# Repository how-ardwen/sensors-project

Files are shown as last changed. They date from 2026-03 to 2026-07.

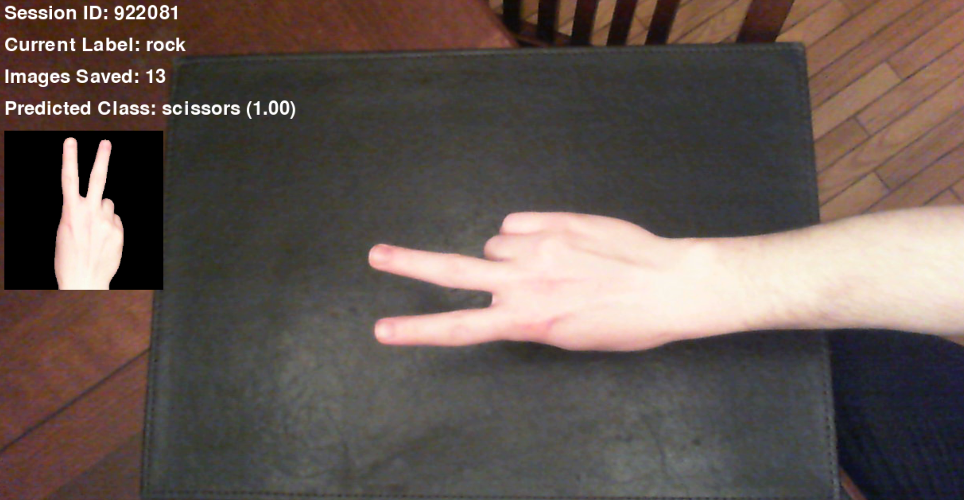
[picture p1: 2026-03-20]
cv_src/prof/HandPhotos/Testing/scissors_02.png

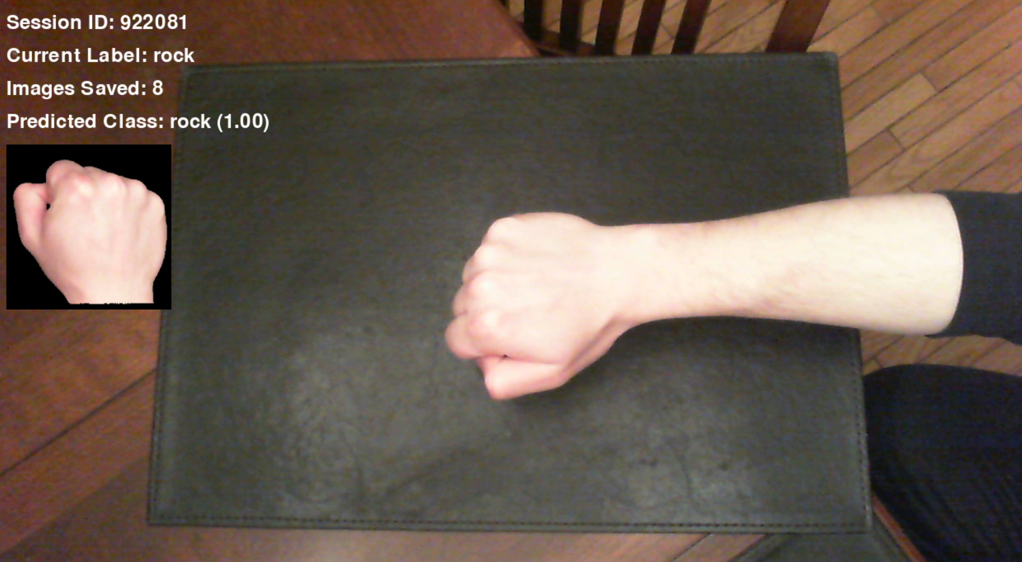
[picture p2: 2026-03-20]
cv_src/prof/HandPhotos/Testing/rock_01.png

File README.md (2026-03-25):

## Communication Protocol

Three ESP32 microcontrollers each connect independently to the laptop over BLE.

---

### MCU 1 — Left Arm  (`RPS-MCU1`)
### MCU 2 — Right Arm  (`RPS-MCU2`)

Packet format: **`H[sign]\n`** (3-byte ASCII + newline)

| Field | Description |
|---|---|
| `H` | Header byte (hand gesture command) |
| `sign` | Gesture code (see table below) |
| `\n` | Newline terminator |

**Gesture Encoding:**

| Value | Gesture | Pinky+Ring | Index+Middle | Thumb |
|---|---|---|---|---|
| `0` | Neutral (rest) | open | open | open |
| `1` | Rock | closed | closed | closed |
| `2` | Paper | open | open | open |
| `3` | Scissors | closed | open | open |

> Neutral (0) is mechanically identical to Paper — all fingers open.

---

### MCU 3 — Swivel Controller  (`RPS-MCU3`)

Packet format: **`S[arm]\n`** (3-byte ASCII + newline)

| Field | Description |
|---|---|
| `S` | Header byte (swivel command) |
| `arm` | Which arm to swivel out of the game window |
| `\n` | Newline terminator |

**Arm Encoding:**

| Value | Action |
|---|---|
| `0` | Both arms in frame |
| `1` | Swivel **left** arm (MCU 1) out of frame |
| `2` | Swivel **right** arm (MCU 2) out of frame |

---

### BLE Service (all three MCUs — Nordic UART Service)

| UUID | Role |
|---|---|
| `6e400001-b5a3-f393-e0a9-e50e24dcca9e` | NUS Service |
| `6e400002-b5a3-f393-e0a9-e50e24dcca9e` | RX Characteristic — laptop writes here |
| `6e400003-b5a3-f393-e0a9-e50e24dcca9e` | TX Characteristic — reserved for future use |

---

### Example Game Flow

| Step | Packet | Target | Meaning |
|---|---|---|---|
| Stage 1 | `H1\n` | MCU 1 | Left arm shows Rock |
| Stage 1 | `H3\n` | MCU 2 | Right arm shows Scissors |
| Stage 2 | `S1\n` | MCU 3 | Swivel left arm out of frame |

Other header bytes are reserved for future message types (e.g., `R\n` for reset).

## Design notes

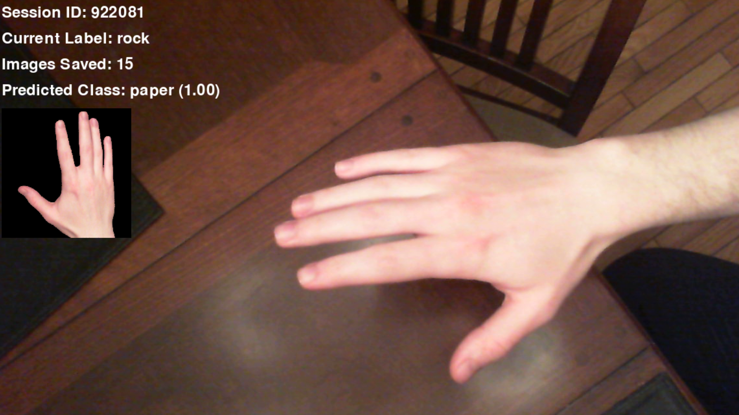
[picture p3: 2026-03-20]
cv_src/prof/HandPhotos/Testing/paper_02.png

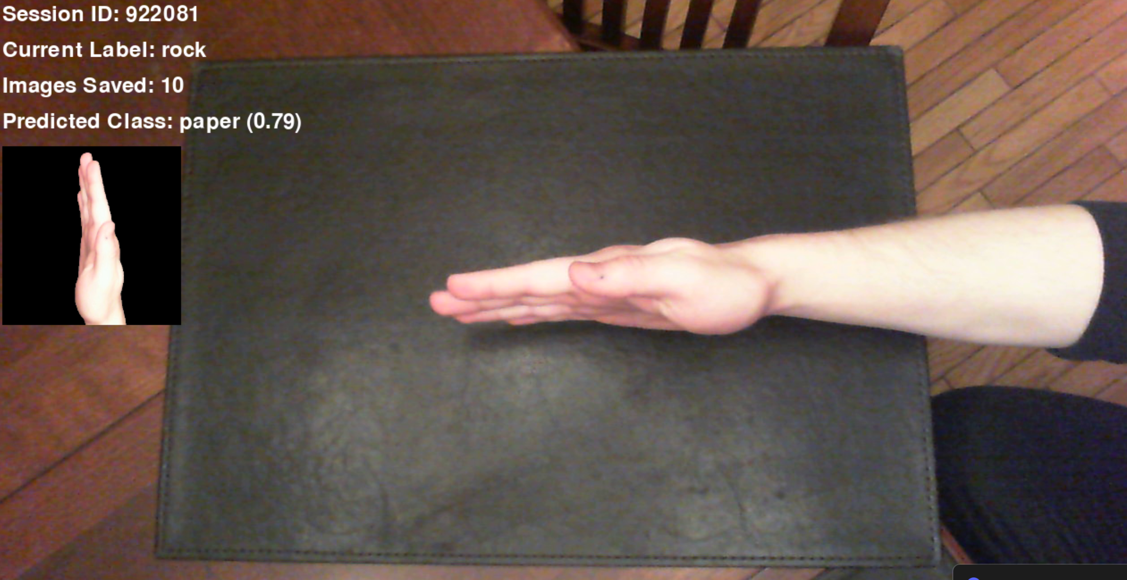
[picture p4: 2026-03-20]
cv_src/prof/HandPhotos/Testing/paper_01.png

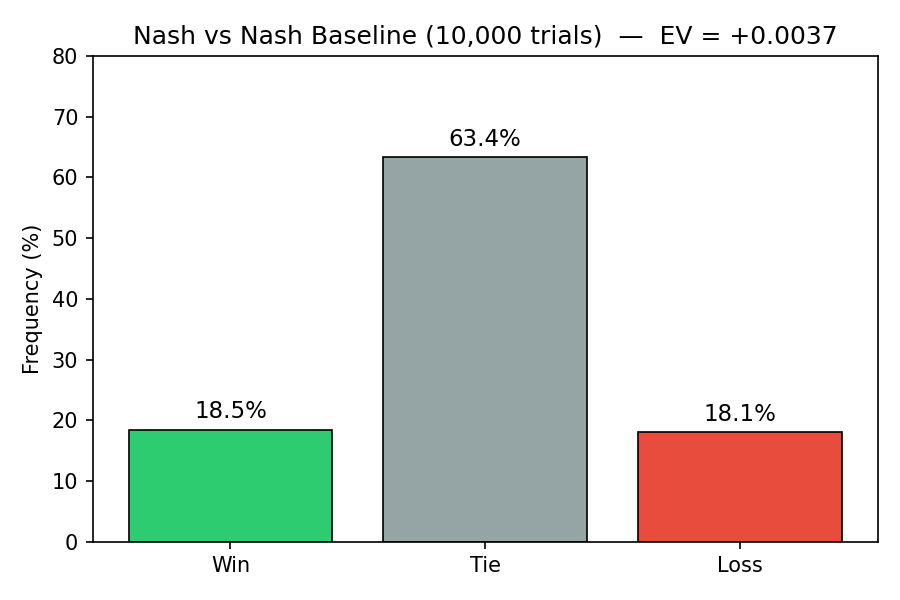
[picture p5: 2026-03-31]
figures/nash_vs_nash.png

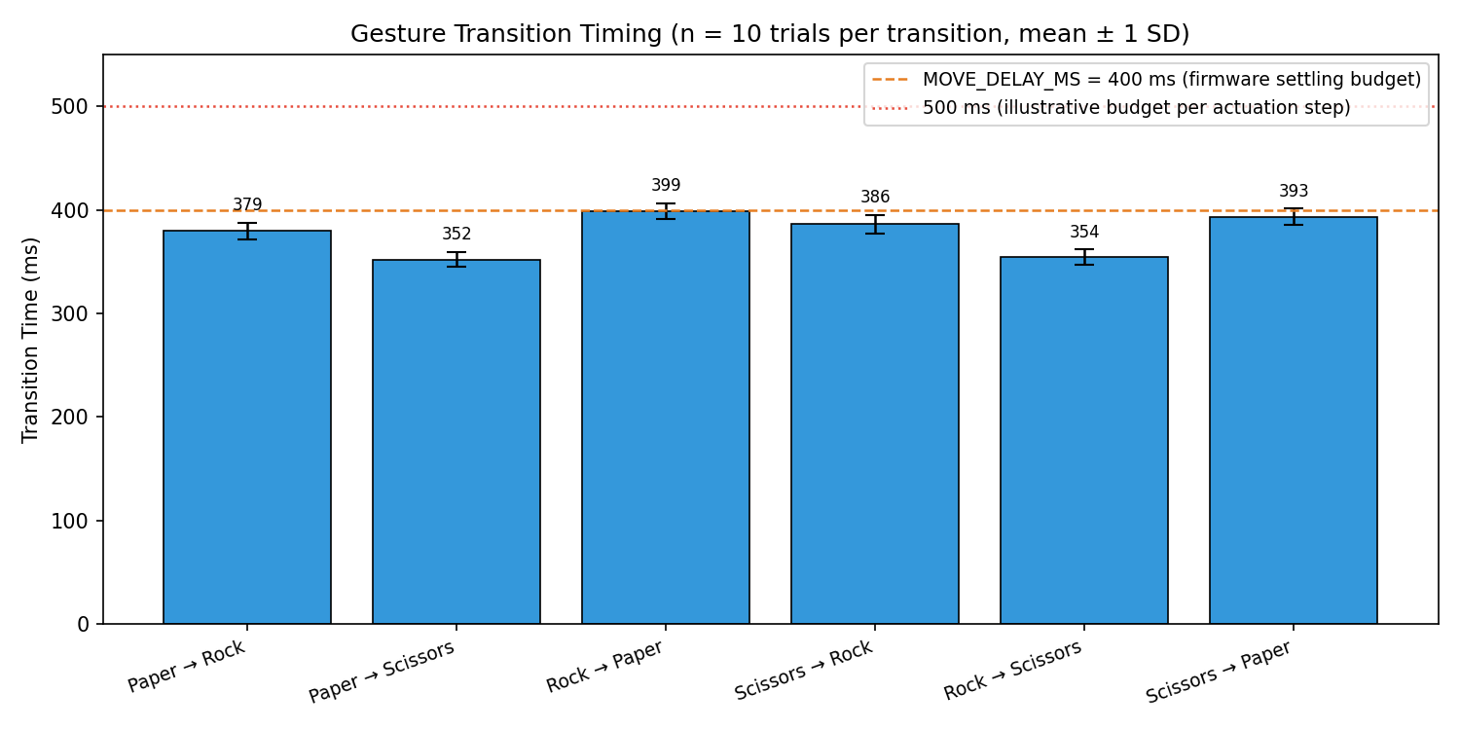
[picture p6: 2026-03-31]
figures/gesture_timing.png

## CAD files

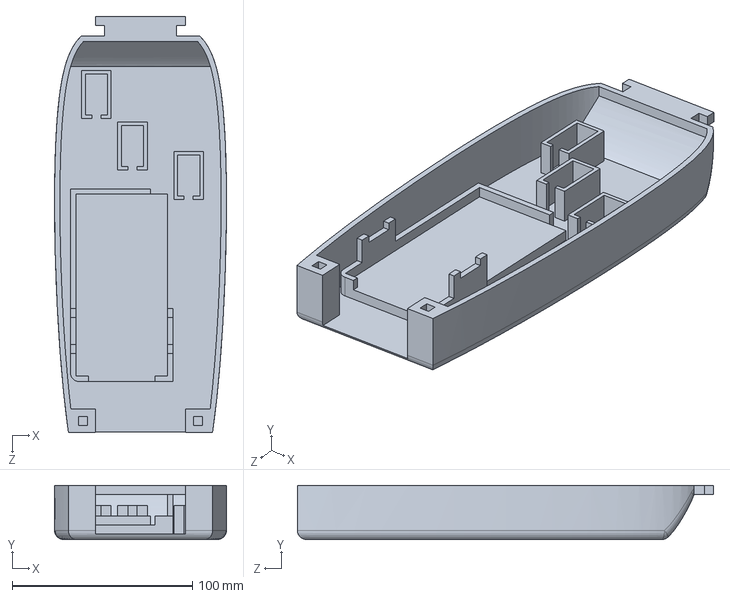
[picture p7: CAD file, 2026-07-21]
CAD/Forearm/Forearm.SLDPRT
95.5 x 30.0 x 231.0 mm

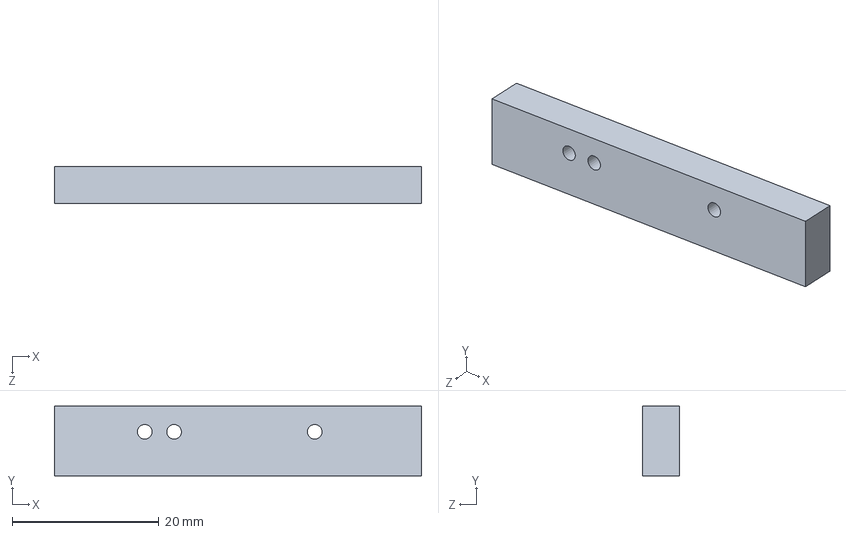
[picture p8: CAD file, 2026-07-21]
CAD/Left_Hand/Left_Hand_Routing_Block.SLDPRT
50.0 x 9.50 x 5.00 mm

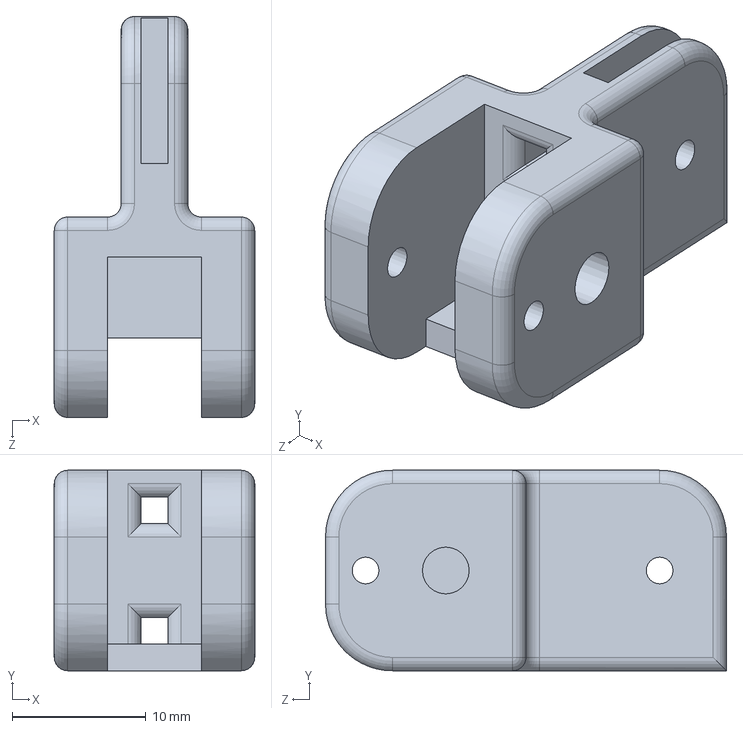
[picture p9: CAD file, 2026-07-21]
CAD/Pointer_Finger/Pointer_Finger_Middle_Section.SLDPRT
15.0 x 15.0 x 30.0 mm

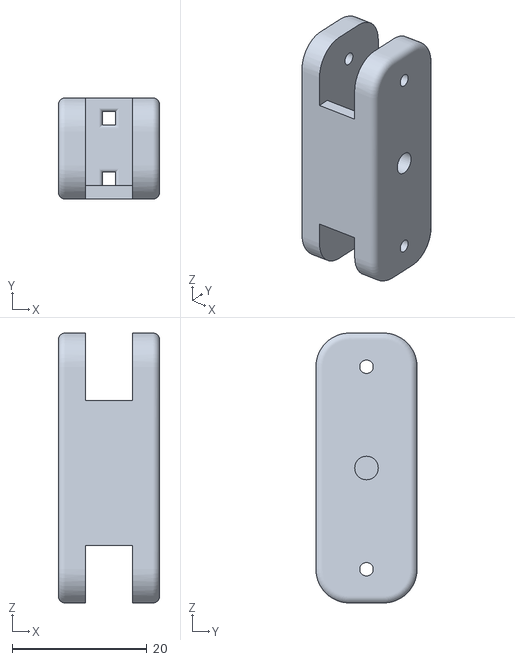
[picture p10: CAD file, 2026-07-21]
CAD/Print_Files/Pointer_Finger_Bottom.STL
15.0 x 15.0 x 40.0

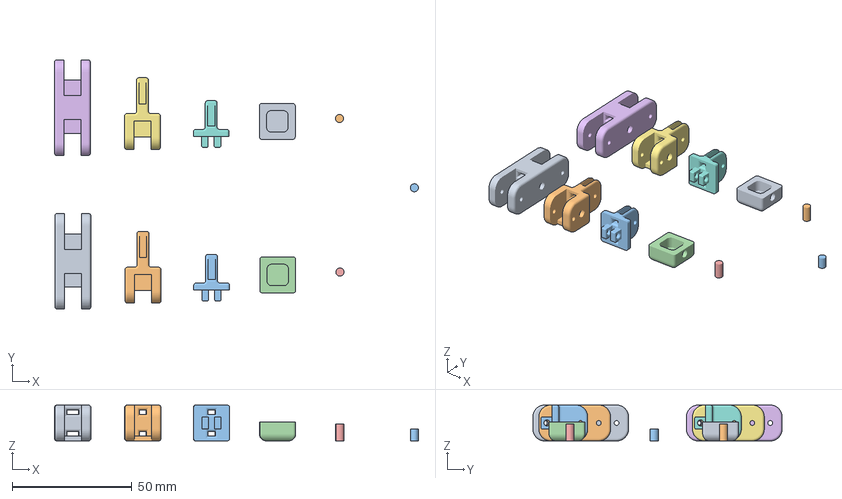
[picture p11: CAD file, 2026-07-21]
CAD/Print_Files/v4/Twofingers.3mf
152.0 x 104.1 x 15.0 mm
Pointer_Finger_Bottom.STL x 2
Pointer_Finger_Middle_Section.STL x 2
Pointer_Finger_Tip.STL x 2
Pointer_Finger_Tip_Cover.STL x 2
Finger_Joint_Connector.STL x 2
Finger_Tip_connector.STL

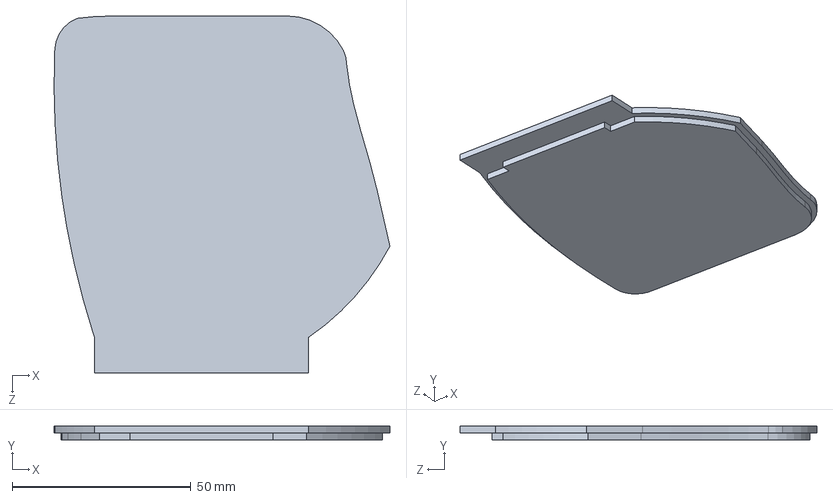
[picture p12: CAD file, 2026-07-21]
CAD/Right_Hand/Palm_Top.SLDPRT
94.1 x 4.00 x 100.0 mm

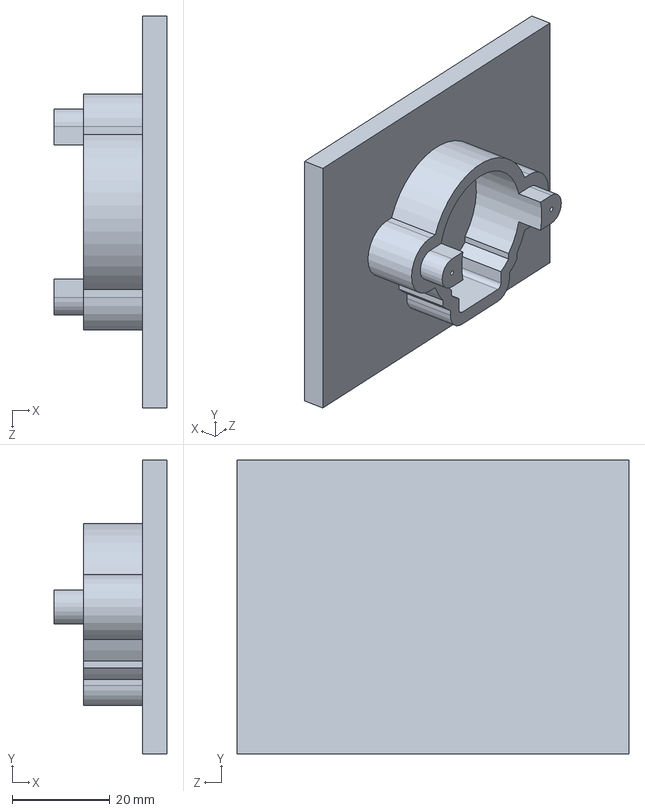
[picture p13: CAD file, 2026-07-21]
CAD/Stepper_Motor_Stuff/Part1.SLDPRT
23.0 x 60.0 x 80.0 mm

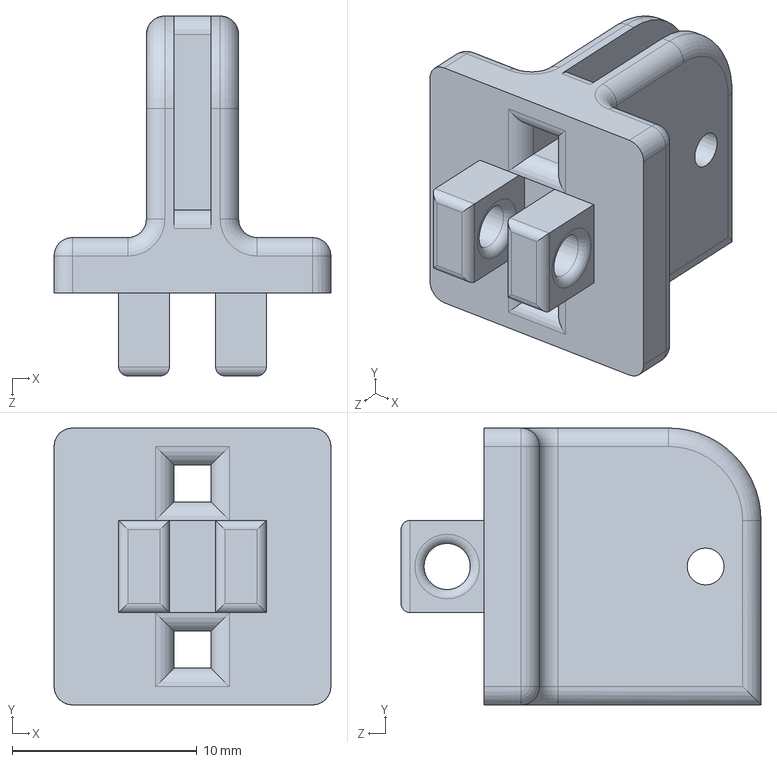
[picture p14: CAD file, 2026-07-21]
CAD/Thumb_Finger/Thumb_Finger_Tip.SLDPRT
15.0 x 15.0 x 19.5 mm

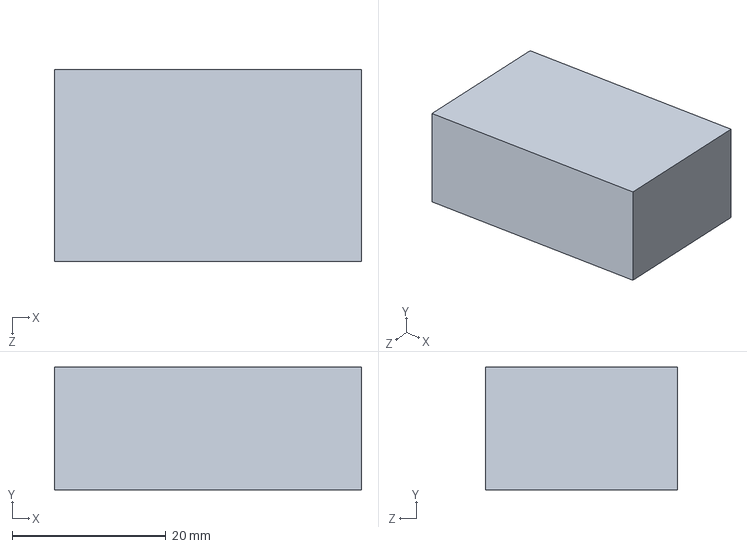
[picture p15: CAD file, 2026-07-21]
CAD/Wheel_Spacers.SLDPRT
40.0 x 16.0 x 25.0 mm

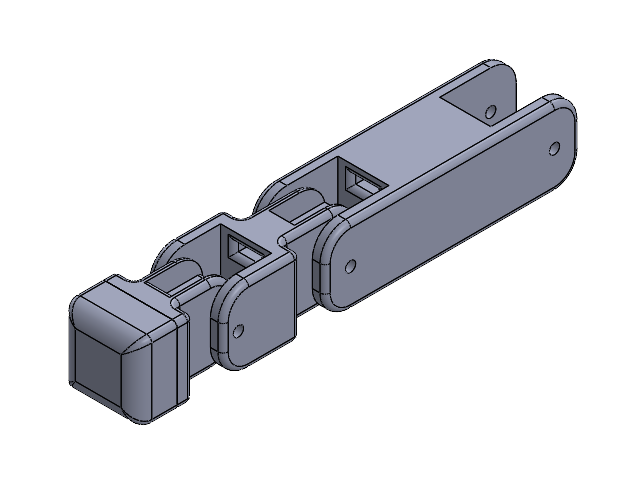
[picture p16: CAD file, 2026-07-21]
CAD/Middle_Finger/Middle_Finger_Assem.SLDASM
Middle_Finger_Bottom
Middle_Finger_Middle_Section
Middle_Finger_Tip
Middle_Finger_Tip_Cover

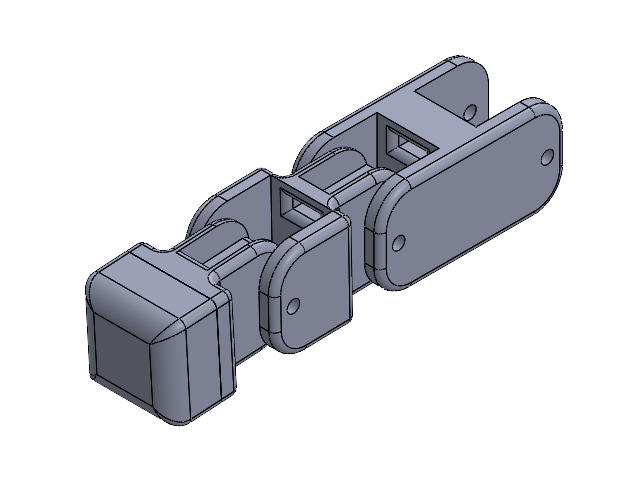
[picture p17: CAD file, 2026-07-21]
CAD/Ring_Finger/Ring_Finger_Assem.SLDASM
Ring_Finger_Bottom
Ring_Finger_Middle_Section
Ring_Finger_Tip
Ring_Finger_Tip_Cover

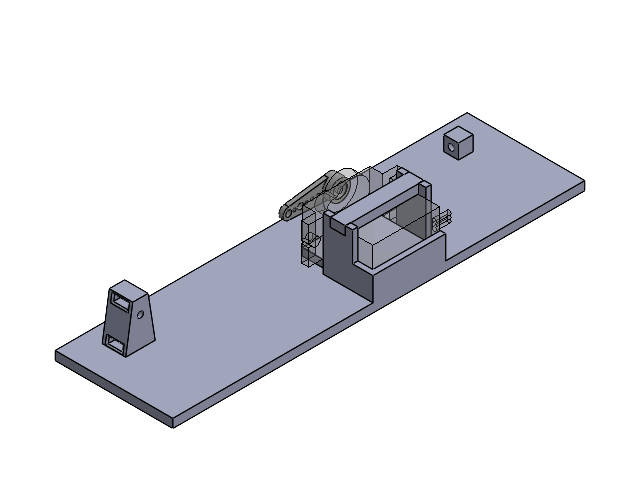
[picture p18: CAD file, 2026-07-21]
CAD/Test_Mount/Test_Mount_Sub_Assem.SLDASM
Test_Mount
servo 25
servo arm single
Servo Holder

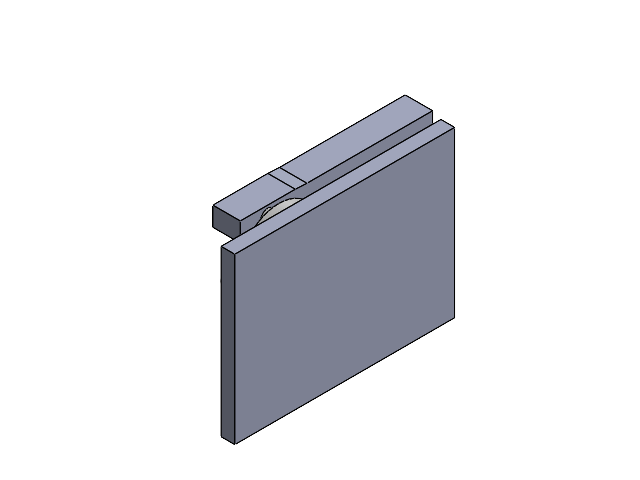
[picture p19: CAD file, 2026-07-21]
CAD/Stepper_Motor_Stuff/Stepper_Test_Assem.SLDASM
Stepper motor 28BYJ-48 5V

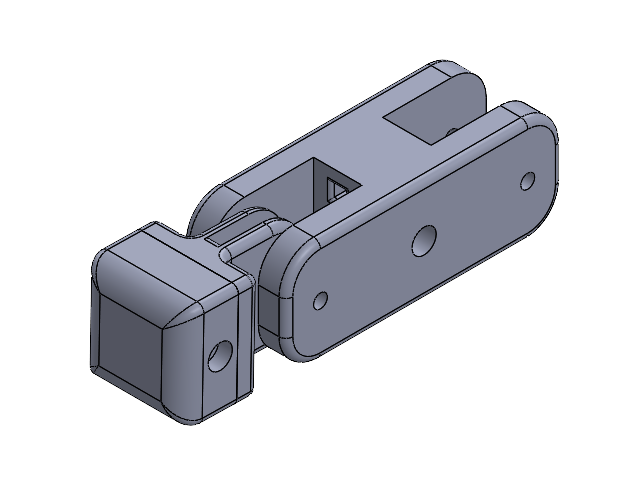
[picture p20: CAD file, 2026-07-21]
CAD/Thumb_Finger/Thumb_Finger_Assem.SLDASM
Thumb_Finger_Bottom
Thumb_Finger_Tip
Thumb_Finger_Tip_Cover

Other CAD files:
CAD/Forearm/Servo_And_Pulley_SubAssem.SLDASM
CAD/Left_Hand/Left_Hand.SLDASM
CAD/Pointer_Finger/Pointer_Finger_Assem.SLDASM
CAD/Right_Hand/Right_Hand_Assem.SLDASM
CAD/Forearm/Forearm_Smaller.SLDPRT
CAD/Forearm/extender_5mm.SLDPRT
CAD/Forearm/servo-pulley-SG90.SLDPRT
CAD/Left_Hand/Left_Hand_Forearm_Bottom.SLDPRT
CAD/Left_Hand/Left_Hand_Palm_Bottom.SLDPRT
CAD/Left_Hand/Left_Hand_Palm_Top.SLDPRT
CAD/Middle_Finger/Middle_Finger_Bottom.SLDPRT
CAD/Middle_Finger/Middle_Finger_Middle_Section.SLDPRT
CAD/Middle_Finger/Middle_Finger_Tip.SLDPRT
CAD/Middle_Finger/Middle_Finger_Tip_Cover.SLDPRT
CAD/Palm_Bottom.SLDPRT
CAD/Pointer_Finger/Finger_Joint_Connector.SLDPRT
CAD/Pointer_Finger/Finger_Tip_connector.SLDPRT
CAD/Pointer_Finger/Pointer_Finger_Bottom.SLDPRT
CAD/Pointer_Finger/Pointer_Finger_Tip_Cover.SLDPRT
CAD/Print_Files/All_Fingers.3mf
CAD/Print_Files/Finger_Joint_Connector.STL
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

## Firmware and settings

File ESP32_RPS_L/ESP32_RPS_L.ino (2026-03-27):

/**
 * ESP32_RPS_L.ino
 * Rock-Paper-Scissors-Minus-One (RPS-1) — ESP32 Firmware
 * MSE 3302B | Western University
 *
 * Receives hand-position commands from the laptop over BLE (Nordic UART
 * Service) and drives servos for finger/thumb gestures and a stepper motor
 * for arm withdrawal.
 *
 * ── Communication Protocol ───────────────────────────────────────────────────
 *   Gesture packet:   P[L][R]
 *     '0' → Withdrawn   '1' → Rock   '2' → Paper   '3' → Scissors
 *     Example: "P13" → Left: Rock, Right: Scissors
 *
 *   Withdraw packet:  W[D]
 *     '1' → Withdraw arm (rotate stepper to out-of-play position)
 *     '0' → Return arm   (rotate stepper back to playing position)
 *     Example: "W1" → Withdraw this arm
 *              "W0" → Return this arm to playing position
 *
 * ── Servo Architecture ───────────────────────────────────────────────────────
 *     FINGER A servo — Index + Middle fingers
 *     FINGER B servo — Ring  + Pinky  fingers
 *     THUMB servo    — Thumb
 *
 *   Gesture mapping:
 *     '0' Withdrawn → fingers open  (180°), thumb tucked   (180°)
 *     '1' Rock      → fingers closed  (0°), thumb tucked   (180°)
 *     '2' Paper     → fingers open  (180°), thumb extended   (0°)
 *     '3' Scissors  → index+middle open (180°), ring+pinky closed (0°), thumb tucked (180°)
 *
 * ── Stepper Architecture ─────────────────────────────────────────────────────
 *   28BYJ-48 stepper via ULN2003 driver board.
 *   Sits completely idle until a W1 or W0 command is received.
 *   ULN2003 IN1 → GPIO 19
 *   ULN2003 IN2 → GPIO 18
 *   ULN2003 IN3 → GPIO  5
 *   ULN2003 IN4 → GPIO  4
 *
 *   WITHDRAW_STEPS controls how far the arm rotates:
 *     512  steps = quarter turn  (90°)
 *     1024 steps = half turn    (180°)
 *     2048 steps = full turn    (360°)
 *
 * ── GPIO Mapping ─────────────────────────────────────────────────────────────
 *               LEFT HAND      RIGHT HAND
 *   Finger A     GPIO 14        GPIO 26
 *   Finger B     GPIO 13        GPIO 25
 *   Thumb        GPIO 27        GPIO 33
 *   Stepper      IN1=19, IN2=18, IN3=5, IN4=4
 *
 * ── BLE Device Names ─────────────────────────────────────────────────────────
 *   Right arm board: #define DEVICE_NAME "RPS-ESP32-R"
 *   Left  arm board: #define DEVICE_NAME "RPS-ESP32-L"
 *   Change this before uploading to each board.
 *
 * ── Dependencies ─────────────────────────────────────────────────────────────
 *   Install via Arduino Library Manager:
 *     • "Adafruit NeoPixel"   by Adafruit
 *     • "ESP32Servo"          by Kevin Harrington
 *     • ESP32 Arduino core    (Board Manager → esp32 by Espressif)
 */

#include <BLEDevice.h>
#include <BLEServer.h>
#include <BLEUtils.h>
#include <BLE2902.h>
#include <Adafruit_NeoPixel.h>
#include <ESP32Servo.h>


// ── Pin / LED configuration ──────────────────────────────────────────────────
#define LED_PIN        21
#define LED_COUNT       1
#define LED_BRIGHTNESS 255


// ── Servo GPIO assignments ────────────────────────────────────────────────────
#define PIN_R_FINGER_A  26    // Right: Index + Middle
#define PIN_R_FINGER_B  25    // Right: Ring  + Pinky
#define PIN_R_THUMB     33    // Right: Thumb

#define PIN_L_FINGER_A  26    // Left: Index + Middle  (not connected yet)
#define PIN_L_FINGER_B  27    // Left: Ring  + Pinky   (not connected yet)
#define PIN_L_THUMB     33    // Left: Thumb            (not connected yet)


// ── Stepper GPIO assignments ──────────────────────────────────────────────────
#define STEPPER_IN1     19
#define STEPPER_IN2     18
#define STEPPER_IN3      5
#define STEPPER_IN4      4


// ── Servo angle constants ─────────────────────────────────────────────────────
#define FINGER_OPEN    180    // String pulled — fingers extended
#define FINGER_CLOSED    0    // String slack  — fingers curl

#define THUMB_TUCKED   150    // Thumb closed
#define THUMB_EXTENDED   0    // Thumb open

#define MOVE_DELAY_MS  500    // ms to wait between each servo movement


// ── Stepper constants ─────────────────────────────────────────────────────────
// Start with 512 (quarter turn) and increase until arm clears play area
#define WITHDRAW_STEPS  1500   // !! tune this value to your mechanism !!
#define STEP_DELAY_US  1200   // microseconds between steps (min ~900)


// ── BLE UUIDs — Nordic UART Service ──────────────────────────────────────────
#define NUS_SERVICE_UUID  "6e400001-b5a3-f393-e0a9-e50e24dcca9e"
#define NUS_RX_CHAR_UUID  "6e400002-b5a3-f393-e0a9-e50e24dcca9e"
#define NUS_TX_CHAR_UUID  "6e400003-b5a3-f393-e0a9-e50e24dcca9e"

// !! CHANGE THIS before uploading to each board !!
// Right arm: "RPS-ESP32-R"
// Left  arm: "RPS-ESP32-L"
#define DEVICE_NAME "RPS-ESP32-L"

#define HAND_VALUE 125


// ── Global objects ────────────────────────────────────────────────────────────
Adafruit_NeoPixel strip(LED_COUNT, LED_PIN, NEO_GRB + NEO_KHZ800);

Servo rightFingerA, rightFingerB, rightThumb;
Servo leftFingerA,  leftFingerB,  leftThumb;

BLEServer*          pServer         = nullptr;
BLECharacteristic*  pTxChar         = nullptr;
bool                deviceConnected = false;


// ── Stepper half-step sequence ────────────────────────────────────────────────
const int stepSequence[8][4] = {
  {1, 0, 0, 0},
  {1, 1, 0, 0},
  {0, 1, 0, 0},
  {0, 1, 1, 0},
  {0, 0, 1, 0},
  {0, 0, 1, 1},
  {0, 0, 0, 1},
  {1, 0, 0, 1}
};

int stepIndex = 0;


// ── stepMotor() — advance stepper one step in given direction ─────────────────
void stepMotor(int direction) {
  stepIndex = (stepIndex + direction + 8) % 8;
  digitalWrite(STEPPER_IN1, stepSequence[stepIndex][0]);
  digitalWrite(STEPPER_IN2, stepSequence[stepIndex][1]);
  digitalWrite(STEPPER_IN3, stepSequence[stepIndex][2]);
  digitalWrite(STEPPER_IN4, stepSequence[stepIndex][3]);
  delayMicroseconds(STEP_DELAY_US);
}


// ── stepperOff() — cut power to all stepper coils ────────────────────────────
void stepperOff() {
  digitalWrite(STEPPER_IN1, LOW);
  digitalWrite(STEPPER_IN2, LOW);
  digitalWrite(STEPPER_IN3, LOW);
  digitalWrite(STEPPER_IN4, LOW);
}


// ── withdraw() — rotate stepper to withdraw or return the arm ─────────────────
void withdraw(bool out) {
  int direction = out ? -1 : 1;
  Serial.printf("[STEPPER] %s arm — %d steps\n",
                out ? "Withdrawing" : "Returning", WITHDRAW_STEPS);
  for (int i = 0; i < WITHDRAW_STEPS; i++) {
    stepMotor(direction);
  }
  stepperOff();
  Serial.println("[STEPPER] Done.");
}


// ── signName() ────────────────────────────────────────────────────────────────
static const char* signName(char sign) {
  switch (sign) {
    case '0': return "Withdrawn";
    case '1': return "Rock";
    case '2': return "Paper";
    case '3': return "Scissors";
    default:  return "Unknown";
  }
}


// ── moveHand() ────────────────────────────────────────────────────────────────
static void moveHand(Servo& fingerA, Servo& fingerB, Servo& thumb, char sign) {
  int targetFingerA, targetFingerB, targetThumb;

  switch (sign) {
    case '0':
      targetFingerA = FINGER_OPEN;
      targetFingerB = FINGER_OPEN;
      targetThumb   = THUMB_TUCKED;
      break;
    case '1':
      targetFingerA = FINGER_CLOSED;
      targetFingerB = FINGER_CLOSED;
      targetThumb   = THUMB_TUCKED;
      break;
    case '2':
      targetFingerA = FINGER_OPEN;
      targetFingerB = FINGER_OPEN;
      targetThumb   = THUMB_EXTENDED;
      break;
    case '3':
      targetFingerA = FINGER_OPEN;
      targetFingerB = FINGER_CLOSED;
      targetThumb   = THUMB_TUCKED;
      break;
    default:
      Serial.printf("[SERVO] Unknown sign '%c' — no movement.\n", sign);
      return;
  }

  fingerA.write(180 - targetFingerA);
  delay(MOVE_DELAY_MS);
  fingerB.write(180 - targetFingerB);
  delay(MOVE_DELAY_MS);
  thumb.write(180 - targetThumb);
  delay(MOVE_DELAY_MS);
}


// ── play() ───────────────────────────────────────────────────────────────────
void play(int hand, char sign) {
  Serial.printf("[SERVO] Hand=%s  Gesture=%s\n",
                hand == 0 ? "LEFT" : "RIGHT", signName(sign));
  if (hand == 0) {
    moveHand(leftFingerA,  leftFingerB,  leftThumb,  sign);
  } else {
    moveHand(rightFingerA, rightFingerB, rightThumb, sign);
  }
}


// ── applyLED() ───────────────────────────────────────────────────────────────
void applyLED(char leftSign, char rightSign) {
  int r = 0, g = 0, b = 0;
  auto addHand = [&](char sign) {
    switch (sign) {
      case '1': r += HAND_VALUE; break;
      case '2': g += HAND_VALUE; break;
      case '3': b += HAND_VALUE; break;
      case '0': break;
      default:  Serial.printf("[LED] Unknown sign '%c'\n", sign); break;
    }
  };
  addHand(leftSign);
  addHand(rightSign);
  r = constrain(r, 0, 255);
  g = constrain(g, 0, 255);
  b = constrain(b, 0, 255);
  strip.setPixelColor(0, strip.Color(r, g, b));
  strip.show();
  Serial.printf("[LED] L='%c' R='%c'  →  RGB(%d, %d, %d)\n",
                leftSign, rightSign, r, g, b);
}


// ── BLE Server Callbacks ──────────────────────────────────────────────────────
class ServerCallbacks : public BLEServerCallbacks {
  void onConnect(BLEServer* pServer) override {
    deviceConnected = true;
    Serial.println("[BLE] Client connected.");
  }
  void onDisconnect(BLEServer* pServer) override {
    deviceConnected = false;
    Serial.println("[BLE] Client disconnected — restarting advertising.");
    pServer->startAdvertising();
  }
};


// ── BLE RX Characteristic Callbacks ──────────────────────────────────────────
class RxCallbacks : public BLECharacteristicCallbacks {
  void onWrite(BLECharacteristic* pChar) override {
    String raw = pChar->getValue();
    Serial.printf("[BLE ←] raw: \"%s\" (%d bytes)\n",
                  raw.c_str(), (int)raw.length());

    // ── Withdraw packet: W[D] ─────────────────────────────────────────────
    if (raw.length() >= 2 && raw[0] == 'W') {
      if (raw[1] == '1') {
        withdraw(true);
      } else if (raw[1] == '0') {
        withdraw(false);
      } else {
        Serial.println("[BLE] Invalid withdraw command. Expected W1 or W0.");
      }
      return;
    }

    // ── Gesture packet: P[L][R] ───────────────────────────────────────────
    if (raw.length() < 3 || raw[0] != 'P') {
      Serial.println("[BLE] Invalid packet — expected P[L][R] or W[D]. Ignoring.");
      return;
    }

    char leftSign  = raw[1];
    char rightSign = raw[2];

    if (leftSign  < '0' || leftSign  > '3' ||
        rightSign < '0' || rightSign > '3') {
      Serial.println("[BLE] Invalid gesture codes. Expected '0'-'3'. Ignoring.");
      return;
    }

    play(0, leftSign);
    play(1, rightSign);
    applyLED(leftSign, rightSign);
  }
};


// ── setup() ──────────────────────────────────────────────────────────────────
void setup() {
  Serial.begin(115200);
  Serial.println("\n[RPS-1] ESP32 firmware starting...");

  // ── Stepper pin init ──────────────────────────────────────────────────────
  pinMode(STEPPER_IN1, OUTPUT);
  pinMode(STEPPER_IN2, OUTPUT);
  pinMode(STEPPER_IN3, OUTPUT);
  pinMode(STEPPER_IN4, OUTPUT);
  stepperOff();
  Serial.println("[STEPPER] Pins initialised — motor idle.");

  // ── Servo init ────────────────────────────────────────────────────────────
  ESP32PWM::allocateTimer(0);
  ESP32PWM::allocateTimer(1);
  ESP32PWM::allocateTimer(2);
  ESP32PWM::allocateTimer(3);

  leftFingerA.setPeriodHertz(50); leftFingerA.attach(PIN_L_FINGER_A, 500, 2400);
  leftFingerB.setPeriodHertz(50); leftFingerB.attach(PIN_L_FINGER_B, 500, 2400);
  leftThumb  .setPeriodHertz(50); leftThumb  .attach(PIN_L_THUMB,    500, 2400);

  play(0, '0');
  Serial.println("[SERVO] Left hand homed to Withdrawn.");

  // ── Boot test sequence ────────────────────────────────────────────────────
  delay(1000);
  Serial.println("[TEST] Starting boot gesture sequence...");
  play(0, '1'); delay(1500);
  play(0, '2'); delay(1500);
  play(0, '3'); delay(1500);
  play(0, '0'); delay(1500);
  Serial.println("[TEST] Boot sequence complete.");

  // ── LED init ──────────────────────────────────────────────────────────────
  strip.begin();
  strip.setBrightness(LED_BRIGHTNESS);
  strip.clear();
  strip.show();
  Serial.printf("[LED] NeoPixel initialised on GPIO %d\n", LED_PIN);

  // ── BLE init ──────────────────────────────────────────────────────────────
  BLEDevice::init(DEVICE_NAME);
  pServer = BLEDevice::createServer();
  pServer->setCallbacks(new ServerCallbacks());

  BLEService* pService = pServer->createService(NUS_SERVICE_UUID);

  BLECharacteristic* pRxChar = pService->createCharacteristic(
    NUS_RX_CHAR_UUID,
    BLECharacteristic::PROPERTY_WRITE | BLECharacteristic::PROPERTY_WRITE_NR
  );
  pRxChar->setCallbacks(new RxCallbacks());

  pTxChar = pService->createCharacteristic(
    NUS_TX_CHAR_UUID,
    BLECharacteristic::PROPERTY_NOTIFY
  );
  pTxChar->addDescriptor(new BLE2902());

  pService->start();

  BLEAdvertising* pAdv = BLEDevice::getAdvertising();
  pAdv->addServiceUUID(NUS_SERVICE_UUID);
  pAdv->setScanResponse(true);
  BLEDevice::startAdvertising();

  Serial.printf("[BLE] Advertising as \"%s\"\n", DEVICE_NAME);
  Serial.println("[RPS-1] Ready — waiting for BLE connection.");
}


// ── loop() ───────────────────────────────────────────────────────────────────
void loop() {
  delay(10);
}

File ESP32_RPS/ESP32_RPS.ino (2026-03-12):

/**
 * ESP32_RPS.ino
 * Rock-Paper-Scissors-Minus-One (RPS-1) — ESP32 Firmware
 * MSE 3302B | Western University
 *
 * Receives hand-position commands from the laptop over BLE (Nordic UART
 * Service) and drives a WS2812B smart LED on GPIO 21 as a placeholder until
 * the mechanical design is finalised.
 *
 * ── Communication Protocol (see README.md) ──────────────────────────────────
 *   Packet:  P[L][R]\n   (4 ASCII bytes + newline)
 *     L / R  = gesture code for left / right hand
 *       '0' → Withdrawn   '1' → Rock   '2' → Paper   '3' → Scissors
 *   Example: "P13\n" → Left: Rock, Right: Scissors
 *
 * ── LED Colour Scheme ────────────────────────────────────────────────────────
 *   Each hand contributes 125 to the channel that matches its sign:
 *     Rock      → Red   += 125
 *     Paper     → Green += 125
 *     Scissors  → Blue  += 125
 *     Withdrawn →  no contribution
 *
 *   Examples:
 *     P11\n  (Rock  | Rock)      → R=250, G=0,   B=0
 *     P22\n  (Paper | Paper)     → R=0,   G=250, B=0
 *     P23\n  (Paper | Scissors)  → R=0,   G=125, B=125
 *     P13\n  (Rock  | Scissors)  → R=125, G=0,   B=125
 *     P03\n  (Withdrawn|Scissors)→ R=0,   G=0,   B=125
 *
 * ── play() Placeholder ───────────────────────────────────────────────────────
 *   void play(int hand, char sign)
 *     hand : 0 = left, 1 = right
 *     sign : '1'=Rock  '2'=Paper  '3'=Scissors  '0'=Withdrawn
 *   Replace the LED logic inside this function with servo / motor calls once
 *   GPIOs are assigned in the mechanical design.
 *
 * ── Dependencies ─────────────────────────────────────────────────────────────
 *   Install via Arduino Library Manager:
 *     • "Adafruit NeoPixel"   by Adafruit
 *     • ESP32 Arduino core    (Board Manager → esp32 by Espressif)
 */

#include <BLEDevice.h>
#include <BLEServer.h>
#include <BLEUtils.h>
#include <BLE2902.h>
#include <Adafruit_NeoPixel.h>

// ── Pin / LED configuration ──────────────────────────────────────────────────
#define LED_PIN        21    // Data pin for the WS2812B smart LED
#define LED_COUNT       1    // Number of LEDs in the strip / ring
#define LED_BRIGHTNESS 255   // Global brightness cap (0–255)

// ── BLE UUIDs — Nordic UART Service (NUS) ────────────────────────────────────
// Must match the UUIDs used in rps.py on the laptop side.
#define NUS_SERVICE_UUID  "6e400001-b5a3-f393-e0a9-e50e24dcca9e"
#define NUS_RX_CHAR_UUID  "6e400002-b5a3-f393-e0a9-e50e24dcca9e"  // laptop → ESP32
#define NUS_TX_CHAR_UUID  "6e400003-b5a3-f393-e0a9-e50e24dcca9e"  // ESP32 → laptop

// ── BLE device name (must match ESP32_BLE_NAME in rps.py) ────────────────────
#define DEVICE_NAME "RPS-ESP32"

// ── Gesture contribution to each RGB channel (per hand) ──────────────────────
#define HAND_VALUE 125   // Each hand contributes this much to its channel

// ── Global objects ────────────────────────────────────────────────────────────
Adafruit_NeoPixel strip(LED_COUNT, LED_PIN, NEO_GRB + NEO_KHZ800);

BLEServer*          pServer    = nullptr;
BLECharacteristic*  pTxChar    = nullptr;
bool                deviceConnected = false;


// ── BLE Server Callbacks ──────────────────────────────────────────────────────
class ServerCallbacks : public BLEServerCallbacks {
  void onConnect(BLEServer* pServer) override {
    deviceConnected = true;
    Serial.println("[BLE] Client connected.");
  }
  void onDisconnect(BLEServer* pServer) override {
    deviceConnected = false;
    Serial.println("[BLE] Client disconnected — restarting advertising.");
    pServer->startAdvertising();
  }
};


// ── play() — Placeholder for mechanical actuation ────────────────────────────
/**
 * Called once per hand per packet. Drives the LED now; replace the body
 * with servo/motor calls when hardware GPIOs are assigned.
 *
 * @param hand  0 = left hand,  1 = right hand
 * @param sign  '0'=Withdrawn  '1'=Rock  '2'=Paper  '3'=Scissors
 */
void play(int hand, char sign) {
  // ── TODO: Replace this section with servo/motor actuation ─────────────────
  //
  //   Example (once GPIO mapping is known):
  //     if (hand == 0) {         // left arm motor
  //       leftArmServo.write(angleForSign(sign));
  //     } else {                 // right arm motor
  //       rightArmServo.write(angleForSign(sign));
  //     }
  //
  // ── LED placeholder — accumulate colour contribution ──────────────────────
  // (Colour is applied in applyLED() after both hands are processed.)

  Serial.printf("  play(hand=%d, sign=%c)\n", hand, sign);
}


// ── applyLED() — Compute and display the blended LED colour ──────────────────
/**
 * Maps each sign to its RGB channel and sums contributions from both hands.
 *
 * @param leftSign   sign character for the left  hand ('0'–'3')
 * @param rightSign  sign character for the right hand ('0'–'3')
 */
void applyLED(char leftSign, char rightSign) {
  int r = 0, g = 0, b = 0;

  // Helper lambda: add one hand's contribution
  auto addHand = [&](char sign) {
    switch (sign) {
      case '1': r += HAND_VALUE; break;   // Rock     → Red
      case '2': g += HAND_VALUE; break;   // Paper    → Green
      case '3': b += HAND_VALUE; break;   // Scissors → Blue
      case '0': /* Withdrawn — no contribution */ break;
      default:  Serial.printf("[LED] Unknown sign '%c'\n", sign); break;
    }
  };

  addHand(leftSign);
  addHand(rightSign);

  // Clamp to 0–255
  r = constrain(r, 0, 255);
  g = constrain(g, 0, 255);
  b = constrain(b, 0, 255);

  strip.setPixelColor(0, strip.Color(r, g, b));
  strip.show();

  Serial.printf("[LED] L='%c' R='%c'  →  RGB(%d, %d, %d)\n",
                leftSign, rightSign, r, g, b);
}


// ── BLE RX Characteristic Callbacks ──────────────────────────────────────────
class RxCallbacks : public BLECharacteristicCallbacks {
  void onWrite(BLECharacteristic* pChar) override {
    String raw = pChar->getValue();
    Serial.printf("[BLE ←] raw: \"%s\" (%d bytes)\n",
                  raw.c_str(), (int)raw.length());

    // ── Validate packet format: P[L][R]\n ─────────────────────────────────
    // Accept with or without trailing newline to be robust.
    if (raw.length() < 3 || raw[0] != 'P') {
      Serial.println("[BLE] Invalid packet — expected P[L][R]\\n. Ignoring.");
      return;
    }

    char leftSign  = raw[1];
    char rightSign = raw[2];

    if (leftSign  < '0' || leftSign  > '3' ||
        rightSign < '0' || rightSign > '3') {
      Serial.println("[BLE] Invalid gesture codes. Expected '0'–'3'. Ignoring.");
      return;
    }

    // ── Dispatch to play() for each hand ──────────────────────────────────
    play(0, leftSign);    // left  hand
    play(1, rightSign);   // right hand

    // ── Update LED ────────────────────────────────────────────────────────
    applyLED(leftSign, rightSign);
  }
};
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

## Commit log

2026-03-23 servo logic added to play function and gpio pins assigned
2026-03-24 fingers working
2026-03-24 stepper motor and working right hand code.
2026-07-21 Add CAD files to repo
    [All_Fingers.3mf, Extended Servo Arm.SLDPRT, Extended Servo Arm.STL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]
